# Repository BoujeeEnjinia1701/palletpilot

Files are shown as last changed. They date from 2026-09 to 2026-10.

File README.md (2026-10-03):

# PalletPilot

     

**Area:** Mobility and Logistics · **TRL:** 3 of 9 (proof of concept on paper) · **Value-engineering target:** $1,610 USD (estimated cost $5,065) · **Difficulty:** 4 of 5

Retrofit kit that turns a manual pallet jack into a powered, walk-behind unit with a UWB follow-me mode and layered stopping.

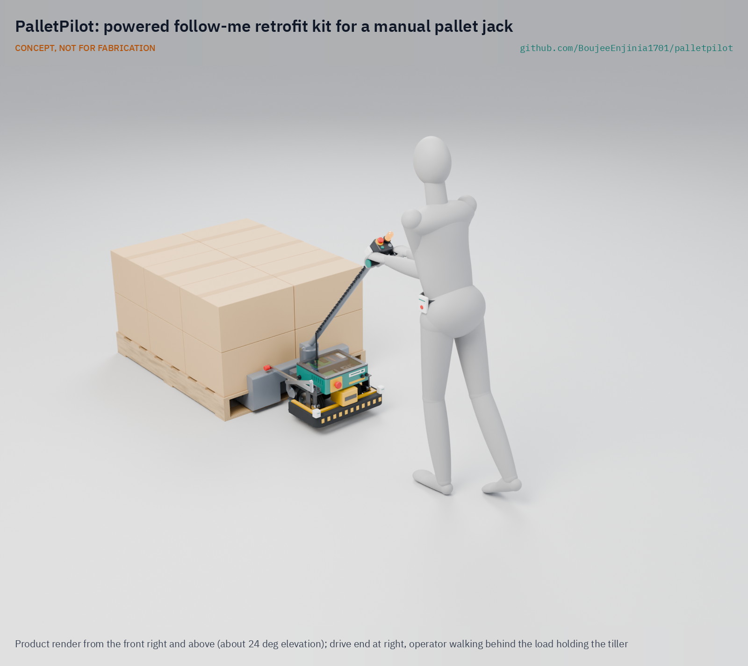
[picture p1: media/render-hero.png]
PalletPilot: powered follow-me retrofit kit for a manual pallet jack, product render


[Exploded render](media/render-exploded.png) · [Detail render](media/render-detail.png) · [Interactive 3D model](media/viewer.html) · [Concept blueprint (PDF)](media/concept-blueprint.pdf) · [General arrangement PLP-DWG-001 (PDF)](cad/drawings/PLP-DWG-001.pdf) · [Sizing calculations](docs/04-calcs/01-sizing.md) · [Prototype build plan](docs/05-build-plan.md) · [Design decisions](docs/06-design-decisions.md) · [Review note](docs/REVIEW.md)

## Concept rationale

Most small sites already own one or more manual pallet jacks, and the jack's forks, pump and load wheels already do the hard part: lifting and carrying the pallet. What the operator lacks is drive and, for picking, a way to stop walking back to the handle. A bolt-on drive module on the steering yoke adds both without touching the jack's load path, and it can be removed to restore the jack. The kit uses parts a small shop can buy or make: AGV hub motors, a 24 V LiFePO4 pack, folded sheet metal, a safety laser scanner and UWB modules.

Keeping the design open matters because the likely users have no dealer service contract. Published drawings, a priced bill of materials and the sizing script let a maintenance person repair it, adapt the clamp to another donor jack, and check the safety numbers for themselves. The kit is a research prototype, not a certified industrial truck.

## Burning platform

Moving loads by hand is one of the most common causes of work injury. In the United States, warehousing and storage recorded 4.8 injury and illness cases per 100 full-time workers in 2024 ([BLS, Warehousing and Storage](https://www.bls.gov/iag/tgs/iag493.htm)), about twice the private industry rate of 2.3 ([BLS, Employer-Reported Workplace Injuries and Illnesses](https://www.bls.gov/news.release/osh.nr0.htm)).

In the European Union, about three in five workers report musculoskeletal complaints, and 52 % of establishments name lifting or moving people or heavy loads as a risk factor ([EU-OSHA, Healthy Workplaces 2020 to 2022](https://healthy-workplaces.osha.europa.eu/en/previous-campaigns/musculoskeletal-disorders-2020-22/what-issue)). Powered trucks remove most of that effort, but small sites with a handful of staff are the ones least able to buy them.

## Where it could be used

### By industry

| Industry | Use |
| --- | --- |
| Small warehousing and third-party logistics | Staging, put-away and loading without a forklift or a second worker |
| Grocery and retail backrooms | Receiving early-morning deliveries and restocking aisles, often by one person |
| Beverage and food distribution | Short, repeated moves of heavy pallets from dock to cooler or truck |
| Light manufacturing and workshops | Moving raw stock and finished goods between machines |
| Maker spaces and training centers | Shared material handling and teaching of safe powered-truck practice |
| Agricultural packhouses | Moving filled crates and bins from packing lines to cold rooms |

### By country or region

| Country or region | Why it matters there |
| --- | --- |
| United States | Warehousing injury rate about twice the private industry average ([BLS](https://www.bls.gov/iag/tgs/iag493.htm)); [OSHA 1910.178](https://www.osha.gov/laws-regs/regulations/standardnumber/1910/1910.178) sets the training and modification-approval route |
| European Union | About three in five workers report musculoskeletal complaints ([EU-OSHA](https://healthy-workplaces.osha.europa.eu/en/previous-campaigns/musculoskeletal-disorders-2020-22/what-issue)); many small distributors and workshops share manual jacks |
| Japan | 29.3 % of the population was 65 or older on October 1, 2024 ([Statistics Bureau of Japan](https://www.stat.go.jp/english/data/jinsui/2024np/index.html)); cutting push force and walking helps older staff keep working |
| India | Scored 3.4 of 5 in the World Bank's 2023 Logistics Performance Index ([World Bank, Connecting to Compete 2023](https://documents1.worldbank.org/curated/en/099042123145531599/pdf/P17146804a6a570ac0a4f80895e320dda1e.pdf)); small distributors that still move pallets by hand could gain a low-cost, locally repairable retrofit instead of importing a complete powered truck |
| Brazil | Scored 3.2 of 5 in the 2023 Logistics Performance Index ([World Bank](https://documents1.worldbank.org/curated/en/099042123145531599/pdf/P17146804a6a570ac0a4f80895e320dda1e.pdf)); small wholesalers and supermarkets that move pallets by hand are the target users |
| South Africa | Scored 3.7 of 5 in the 2023 Logistics Performance Index ([World Bank](https://documents1.worldbank.org/curated/en/099042123145531599/pdf/P17146804a6a570ac0a4f80895e320dda1e.pdf)); distributors and packhouses could fit a kit built from commodity parts and maintain it locally |

## What sparked the idea

The starting point was Piaggio Fast Forward's gita, a personal cargo robot that went on sale on November 18, 2019 for $3,250. At the push of a button it pairs with its leader and uses visual sensors to follow them at up to about 2.7 m/s (6 mph), carrying up to about 18 kg (40 lb) ([Piaggio Fast Forward press release, October 15, 2019](https://www.globenewswire.com/news-release/2019/10/15/1929794/0/en/Piaggio-Fast-Forward-Introduces-the-All-New-gita-Robot.html)). At the other end of the scale, follow-me operation for pallets comes as an option on full order-picking trucks: Jungheinrich's easyPILOT Follow lets its low-level order pickers follow an operator who wears a control unit ([Jungheinrich](https://www.jungheinrich.com/en/press-events/press-releases/easypilot-follow-faster-order-picking-with-the-new-semi-automatic-control-unit-158956)). Nothing sat between them: a follow-me mode for a 1,000 kg pallet at a price a small site can pay. PalletPilot fills that gap by adding the follow-me mode, with layered stopping, to the manual jack the site already owns.

## Problem

Small warehouses move pallets by hand, and powered pallet trucks with follow-me modes cost more than they can justify. Starting a 1,000 kg pallet on a manual jack takes about 270 N (estimate, PLP-CAL-001), at or past common ergonomic push limits. Basic lithium walkies now cost about $1,640, but follow-me trucks are forklift-class products. Full problem statement: [docs/01-problem.md](docs/01-problem.md)

## Concept

Retrofit kit that turns a manual pallet jack into a powered, walk-behind unit with a UWB follow-me mode and layered stopping.

A sprung module with two 24 V hub motors clamps to the jack's steering yoke, with a 25.6 V 20 Ah LiFePO4 pack and the electronics in a low enclosure under the handle's sweep. In walk mode the operator steers with the handle and a walkie-style tiller head. With the kit fitted the handle turns about 40° each way, set by rubber stops (a bare jack turns about 90°), so the jack turns more widely than before: a turning radius of roughly 1.5 m about the load wheels, to be confirmed in the TRL 4 aisle test. In follow mode the operator wears a UWB tag and the motors steer by differential drive to hold a 1.5 m gap. Stopping is layered: a safety laser scanner watches a 0.80 m field ahead of the truck in follow mode, hardwired emergency stops act through a dual-channel safety relay and two contactors in series, and a contact bumper is the last layer.

The sizing note ([PLP-CAL-001](docs/04-calcs/01-sizing.md)) finds that the kit moves 1,000 kg, starts on a 2 % ramp, works a 60-move shift with 24 % of the pack left and stops from 0.6 m/s in 0.36 to 0.70 m. Two targets are missed on paper: follow bearing accuracy (about ±16° against ±10°) and the 40 kg kit mass goal (42.9 kg, inside the 45 kg prototype limit). Value-engineering target: USD 1,610. Estimated cost of the constructable design: USD 5,065 (USD 3,455 over the target), because personnel detection now uses a safety-rated laser scanner. With the kit fitted the jack steers about 40° each way, against about 90° bare. Requirement status is in [docs/03-requirements.md](docs/03-requirements.md); decisions are in [PLP-DDR-001](docs/decisions/0001-trl2-review-decisions.md) and [PLP-DDR-002](docs/decisions/0002-recommendations-accepted.md); the changes that made the design buildable are in [PLP-DDR-003](docs/decisions/0003-design-for-construction.md).

Full design precis: [docs/02-concept.md](docs/02-concept.md)

## Key components

- Drive module with two 24 V, 200 mm hub motors and spring-applied brakes
- Dual-channel motor driver
- 25.6 V 20 Ah LiFePO4 pack with BMS
- Tiller control head with throttle, belly-reverse paddle and mode key
- Two hardwired emergency stops, a safety relay and two main contactors
- Safety laser scanner (PL d class) for personnel detection in follow mode, to ISO 3691-4
- Contact bumper (safety edge) as the last layer
- Three UWB anchors and an operator tag
- ESP32-S3 class controller

The working bill of materials is in [bom/bom.csv](bom/bom.csv).

## Building the prototype

The [prototype build plan](docs/05-build-plan.md) (PLP-BLD-001) shows how to make each of the 17 components and fit them to a donor jack in 15 steps, with a making sketch for every made part, close-ups of the joints and a picture for every step. Eleven parts are cut, drilled, welded or folded in a small fabrication shop; the motors, battery, electronics, safety edge, safety scanner and tiller head are bought. The subframe grips the jack's yoke plate between a top plate and a bolted jaw, so nothing on the jack is drilled. It is a plan, not a record of a build: building and testing to it is TRL 4 work. Decisions still open are in the [design decisions register](docs/06-design-decisions.md).

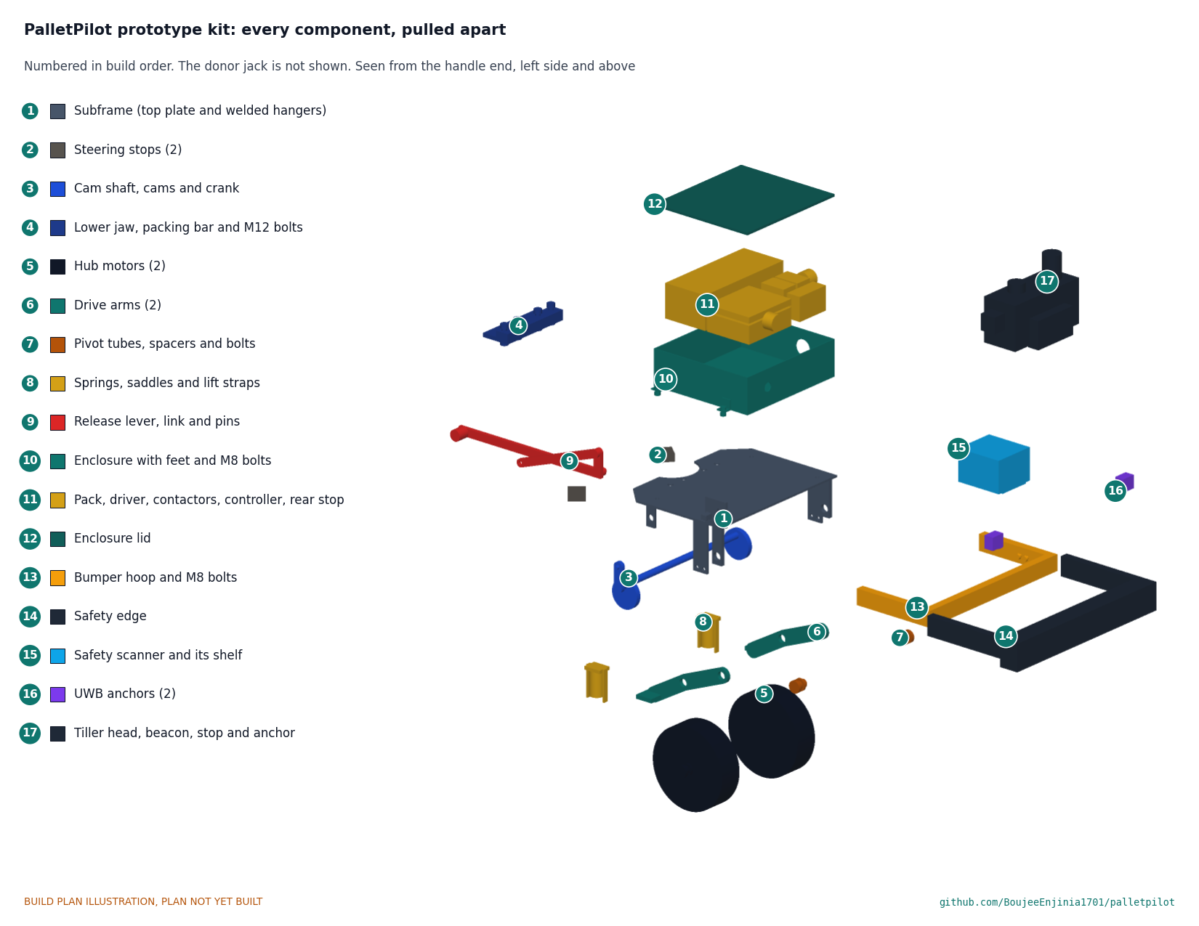
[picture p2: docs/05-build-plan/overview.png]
PalletPilot kit: every component pulled apart and numbered in build order


## Safety

> Moving machinery near people. The design uses hardwired emergency stops, walking-pace speed limits, a safety laser scanner stop layer in follow mode and a bumper that stops the unit on contact. The scanner layer is not yet built or tested, so follow mode stays at 0.15 m/s or less in a closed area until the layer is built and tested. Follow mode is treated as a driverless truck function under ISO 3691-4, so its personnel detection and stopping functions must meet that standard before any trial with people present. Contains a lithium battery pack. Use a BMS with cell-level protection, fuse the pack, and charge on a non-combustible surface. In the United States a powered pallet jack needs trained operators and the jack maker's written approval for modifications (29 CFR 1910.178). Builds are research prototypes, not certified industrial trucks. See [docs/02-concept.md](docs/02-concept.md#safety).

## Repository layout

| Folder | Contents |
| --- | --- |
| `docs/` | Problem, concept, requirements, calculations and design decisions |
| `cad/src/` | build123d Python source, the source of truth for all geometry |
| `cad/step/`, `cad/stl/` | Exported models for FreeCAD, other CAD tools and printing |
| `cad/drawings/` | General arrangement PLP-DWG-001 (generated by `cad/src/sheets.py`) |
| `bom/` | Bill of materials |
| `electronics/` | KiCad schematics and PCB layouts |
| `firmware/` | Microcontroller code |
| `media/` | Renders, perspectives and photos |
| `build-log/` | Dated prototyping notes |

## Documentation

Controlled documents follow the portfolio [documentation standard](.kit/STANDARDS.md). Each carries a document ID (PLP-PRC-001 for the precis), a version and a revision history. Branded PDFs are built with `python .kit/render.py` and attached to GitHub Releases when a document is tagged, for example `PLP-PRC-001/v1.0`.

## Credits

Designed by Amish Chadha. See [CONTRIBUTORS.md](CONTRIBUTORS.md) for roles. To cite this design, use [CITATION.cff](CITATION.cff) (GitHub shows it as "Cite this repository").

AI assistance (Claude) was used to accelerate concept renders, prototype documentation and first-pass sizing calculations. Design direction and all decisions are Amish Chadha's, recorded in this repository's decision records (`docs/decisions/`).

## Licenses

- **Hardware** (CAD, drawings, BOM, electronics): [CERN-OHL-S v2](LICENSE)
- **Software** (firmware, scripts, notebooks): [MIT](LICENSE-SOFTWARE)

A project of the [Design Molecule](https://designmolecule.com) lab.

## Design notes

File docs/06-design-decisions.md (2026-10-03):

---
doc_id: PLP-DEC-001
title: PalletPilot design decisions register
project: PalletPilot
doc_type: Design decisions register
version: "0.6"
status: Draft
date: '2026-10-03'
author: Amish Chadha
license: CERN-OHL-S-2.0
revisions:
  - version: "0.1"
    date: '2026-10-01'
    author: Amish Chadha
    change: Register opened with the build plan; open decisions from PLP-DDR-001 to 003 and the review note; budget treated as a value-engineering target
  - version: "0.2"
    date: '2026-10-01'
    author: Amish Chadha
    change: Amish accepted the recommendation of open item 1 (steering range, option a, with a TRL 4 aisle test as a go or no-go gate; PLP-DDR-003 A1); moved to decisions made; open items renumbered 1 to 5
  - version: "0.3"
    date: '2026-10-02'
    author: Amish Chadha
    change: "Amish approved the recommendations for all five open decisions; moved to decisions made; To confirm item 1 and the value engineering note updated"
  - version: "0.4"
    date: '2026-10-02'
    author: Amish Chadha
    change: "Design for construction (PLP-DDR-003, Table 1, P1 to P10) accepted by Amish on 2026-10-02; the 2026-09-30 row no longer says open for review"
  - version: "0.5"
    date: '2026-10-02'
    author: Amish Chadha
    change: "Approved follow-ups carried out: row added to decisions made; value engineering section restated (safety scanner, USD 5,065, 42.9 kg); To confirm items 4, 5 and 6 updated"
  - version: "0.6"
    date: '2026-10-03'
    author: Amish Chadha
    change: "Amish accepted the PL d safety scanner at USD 3,455 and the kit estimate of about USD 5,065 against the USD 1,610 target (2026-10-03); row added to decisions made; value engineering section updated"
---

# PalletPilot design decisions register

Every design decision still to be made, and every decision made, in one place. Each decision is argued in full in its decision record under `docs/decisions/`; this register is the index Amish works from. The build plan (`docs/05-build-plan.md`) describes the design as it stands and does not list open decisions.

## Open decisions

None. All open decisions were decided on 2026-10-02.

## To confirm when parts are bought

| # | What to confirm | Why it matters | Source |
| --- | --- | --- | --- |
| 1 | The donor jack's yoke plate thickness, rear edge position and width, the pump diameter, and the distance from the steering axis to the frame head, for each of the three jacks in the donor survey decided on 2026-10-02 (a Crown PTH 50 series class model, a distributor's standard model such as Uline's, the Harbor Freight Pittsburgh 5,500 lb jack) | They set the packing bar, the clamp holes, the notch and the steering stop angle | PLP-DDR-003; R1 |
| 2 | The hub motor's 24 V winding, peak torque (30 N·m or more), brake holding torque (20 N·m or more), mass and its shaft's diameter and flats | They set the drive arm's axle hole and the mass and stopping figures | PLP-DDR-002; PLP-CAL-001 |
| 3 | The preload spring: about 34 mm outside diameter, about 65 mm free length, about 100 N/mm | It sets the 750 N per wheel preload and the 10 mm wheel lift | PLP-DDR-003; PLP-CAL-001 [G4] |
| 4 | The safety edge profile's travel (40 mm or more at the front, now 68 mm high), its evaluation unit's category and response time | R8's 0.15 m/s limit rests on 40 mm of travel and a 100 ms chain | PLP-DDR-002; R8 |
| 5 | The tiller head fits the donor handle tube and carries the beacon, stop and anchor | The head clamps on the handle; the grip width is still open in the appearance model | REVIEW (2026-09-26) |
| 6 | The safety scanner's mounting holes, its scan plane height above its base (about 40 mm assumed), its response time (70 ms assumed) and the exact size of its body (about 107 x 80 x 118 mm assumed) | The bracket shelf is drilled to suit, they set the 173 mm scan plane and the 0.80 m protective field, and the body must clear the enclosure by 5 mm | PLP-DDR-003; ISO 3691-4 decision of 2026-10-02 |

## Value engineering

Value-engineering target: USD 1,610 (a hypothetical control target, not a limit). Estimated cost of the constructable design: USD 5,065 (USD 3,455 over the target). Main cost drivers and savings worth trying:

Amish accepted this overrun on 2026-10-03: the safety scanner line of USD 3,455 and the kit estimate of USD 5,065 against the USD 1,610 target (USD 3,455 over). Amish: "PalletPilot - i accept it". Amish: "Cost over target - i accept all the cost variations and overruns". It stays reported against the target as an accepted overrun, and the savings below remain worth trying.

- The safety laser scanner for personnel detection is USD 3,455 (USD 3,444.30 listed for a SICK nanoScan3 class unit, plus a shelf), 68 % of the kit. It replaced a USD 80 lidar line when Amish decided on 2026-10-02 that follow mode is treated under ISO 3691-4. The next largest lines are the two hub motors (USD 400), the battery (USD 180), the motor driver (USD 150), the drive module (USD 130) and the contact bumper (USD 110).
- Making the design constructable added USD 80: the drive module with its clamp, arms and pivot (USD 90 to USD 130), the release mechanism with its cams, link, springs and straps (USD 20 to USD 45), the enclosure feet (USD 5) and the steering stops (USD 10).
- The 5 mm top plate, tube lever and hollow pivots decided on 2026-10-02 are in the model and cut the kit mass by about 2.0 kg (kit now 42.9 kg); they change no price.
- Savings worth trying: a smaller or cheaper safety scanner that still meets PL d and fits in front of the enclosure (a refurbished Hokuyo UAM-05LP-T301 is listed at USD 1,347.53 but its 143 x 110 x 110 mm body does not fit as the kit is laid out), a motor sold with its driver as a pair (the class prices run from USD 165 to USD 249 per motor), and batching the laser-cut plate parts into one order.

## Decisions made

| Date | Decision | Decided by | Record |
| --- | --- | --- | --- |
| 2026-09-25 | TRL 2 review items D1 to D9: layered stopping with a low-cost lidar layer, budget, dual hub motors on a sprung yoke module, 24 V LiFePO4, everything on the yoke, speeds, kit rating, legal route, partner types | Amish: "proceed with all of your recommendations across all batches. Make sure we don't proceed to TRL 4 on any of them." | PLP-DDR-001 |
| 2026-09-25 | Bumper-only speed limited to 0.15 m/s (O4); mass and cost overruns accepted for now, R5 fixes evaluated at TRL 4 (O5); a second main contactor in series (O6) | Amish: "i accept all your recommendations, go with them across all repos." | PLP-DDR-002 |
| 2026-09-26 | Budget set to USD 1,610 to cover the priced BOM | Amish: "i approve all the budget items." | PLP-DDR-002 v0.2 |
| 2026-09-30 | Make the design physically buildable while drawing the build plan; outstanding decisions go in this register, not in the build plan | Amish: "If you are realising that the design cannot be built as per concept - fix the design assumptions to match and be physically feasible as you draw the illustrations." The changes themselves were accepted on 2026-10-02 (below) | PLP-DDR-003 |
| 2026-10-01 | The budget is a value-engineering target, reported as over or under, never as a limit | Amish: "the budgets are a hypothethical control target to ensure we are thinking along a value engineering lens." | This register; PLP-CAL-001 v0.4 |
| 2026-10-01 | Steering range (open item 1 in register v0.1): option (a). Accept about 40° each way with the kit fitted for the prototype (a bare jack turns about 90°), turning radius roughly 1.5 m about the load wheels; set the rubber stops from the donor survey; the precis, README and requirements no longer say the kit steers like the bare jack. **Go or no-go gate:** the TRL 4 aisle test must show the kit can make a right-angle turn into a standard pallet bay; if it cannot, the drive layout changes before TRL 5 (option c, for example one centre drive wheel under the yoke, which reopens D3) | Amish: "i accept your recommendations for PalletPilot" | PLP-DDR-003, A1 |
| 2026-10-02 | Kit mass of 44.4 kg accepted for the prototype (option a); R15's prototype limit restated as 45 kg, rechecked at the motor quote, and the 1.5 kg of savings of option (b) (5 mm top plate, tube lever, hollow pivot pin) carried into the TRL 4 drawings (open item 1) | Amish: "i approve your recommendations for all 555 open decisions." | PLP-DDR-003, A2 |
| 2026-10-02 | Drive wheel lift of 10 mm accepted for smooth indoor floors (option a); the build plan states that the release is for indoor floors only (open item 2) | Amish: "i approve your recommendations for all 555 open decisions." | PLP-DDR-003, A3 |
| 2026-10-02 | Follow mode is treated as a driverless truck function under ISO 3691-4, with personnel detection and stopping functions to that standard; it is reclassified as an operator-controlled assist mode only if a standards body or a notified body confirms that the walking follower counts as the operator (open item 3) | Amish: "i approve your recommendations for all 555 open decisions." | PLP-DDR-001, O2 |
| 2026-10-02 | Donor jacks to support first: a survey of three widely sold 27 x 48 in, 2,500 kg hand pallet jacks with published dimensioned drawings, a professional model such as the Crown PTH 50 series, a distributor's standard model such as Uline's, and the low-cost Harbor Freight Pittsburgh 5,500 lb jack (open item 4) | Amish: "i approve your recommendations for all 555 open decisions." | PLP-DDR-001, O3 |
| 2026-10-02 | Partners near Irving: Dallas Makerspace as the first candidate maker space, and a small food bank or charity warehouse in the Dallas and Fort Worth area as the first candidate warehouse, which trials only after the jack maker's written approval under D8 (open item 5) | Amish: "i approve your recommendations for all 555 open decisions." | PLP-DDR-001, O1 |
| 2026-10-02 | Design for construction accepted: the changes P1 to P10 in Table 1, as made | Amish: "APPROVED: Design-for-construction changes in 10 repos (CityTwin, CoolShade, PalletPilot, Heliolite, PotholeLog, EarthPress, ReadyKit, CellCheck, CargoMule and ThermaCart)" | [PLP-DDR-003](decisions/0003-design-for-construction.md), Table 1 |
| 2026-10-02 | Every follow-up action of the open-decision sign-off that needs CAD, drawing, picture, BOM or calculation work is carried out: the 5 mm top plate, tube lever and hollow pivots in the model; a safety laser scanner (SICK nanoScan3 class) in place of the lidar with the personnel stop to ISO 3691-4 stop category 1 and the R7 case rerun; R15a restated to 45 kg in the script. The donor survey dimensions (packing bar, clamp holes, notch, stop angle) wait for the surveyed jacks | Amish: "APPROVED CHANGES, COMPLETE THESE" | [REVIEW.md](REVIEW.md), session 2026-10-02 (approved follow-ups carried out) |
| 2026-10-03 | Safety laser scanner at PL d (SICK nanoScan3 class) at USD 3,455 accepted; the kit estimate of about USD 5,065 against the USD 1,610 value-engineering target (USD 3,455 over) accepted | Amish: "PalletPilot - i accept it"; and "Cost over target - i accept all the cost variations and overruns" | [REVIEW.md](REVIEW.md), session 2026-10-03; PLP-DEC-001, Value engineering |

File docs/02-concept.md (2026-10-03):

---
doc_id: PLP-PRC-001
title: PalletPilot design precis
project: PalletPilot
doc_type: Design precis
version: "0.9"
status: Draft
date: '2026-10-02'
author: Amish Chadha
license: CERN-OHL-S-2.0
revisions:
- version: "0.1"
  date: '2026-09-24'
  author: Amish Chadha
  change: Initial scaffold
- version: "0.2"
  date: '2026-09-25'
  author: Amish Chadha
  change: Populate to TRL 2 (architecture, first-order numbers, stopping analysis, safety, media)
- version: "0.3"
  date: '2026-09-25'
  author: Amish Chadha
  change: Record decisions PLP-DDR-001 (layered stopping with a lidar layer, budget, drive, power, mounting, speeds, rating, legal route); numbers replaced by PLP-CAL-001; layout revised for handle clearance and length
- version: "0.4"
  date: '2026-09-25'
  author: Amish Chadha
  change: Recommendations accepted by Amish (DDR-002)
- version: "0.5"
  date: '2026-09-26'
  author: Amish Chadha
  change: Budget approved by Amish ($1,610, PLP-DDR-002); cost status restated
- version: "0.6"
  date: '2026-10-01'
  author: Amish Chadha
  change: "Constructable design (PLP-DDR-003): drive module, release, mass, cost and steering range; budget as a value-engineering target"
- version: "0.7"
  date: '2026-10-01'
  author: Amish Chadha
  change: Steering range decided by Amish (PLP-DDR-003 A1, option a); range and turning radius stated in the summary and walk mode, with the TRL 4 aisle test as a go or no-go gate
- version: "0.8"
  date: '2026-10-02'
  author: Amish Chadha
  change: "Follow mode classification, donor survey, partners, R15 and wheel lift decided by Amish on 2026-10-02 (PLP-DEC-001)"
- version: "0.9"
  date: '2026-10-02'
  author: Amish Chadha
  change: "Approved follow-ups carried out: safety laser scanner replaces the lidar (ISO 3691-4), 5 mm top plate, tube lever and hollow pivots; mass, stopping and cost figures from PLP-CAL-001 v0.7"
---

# PalletPilot design precis

PalletPilot clamps a drive module with two 24 V hub motors to the steering yoke of an ordinary manual pallet jack, powers it from a 25.6 V LiFePO4 pack in a low enclosure on the same yoke, and adds a walkie-style tiller head, a UWB follow-me mode and layered stopping: hardwired emergency stops, a safety laser scanner stop layer in follow mode and a contact bumper as the last layer. The calculation note PLP-CAL-001 shows the kit can move a 1,000 kg pallet at walking pace for a full shift of 60 moves on one overnight charge, start on a 2 % ramp, and stop from follow-mode speed inside the scanner's field without reaching the operator it follows. Two targets are missed on paper: follow bearing accuracy (about ±16° against ±10°) and the 40 kg kit mass goal (42.9 kg, inside the 45 kg prototype limit). Value-engineering target: USD 1,610. Estimated cost of the constructable design: USD 5,065 (USD 3,455 over the target), because personnel detection now uses a safety-rated scanner. The design was made constructable on 2026-10-01 (PLP-DDR-003, Draft) and the prototype build plan is PLP-BLD-001; with the kit fitted the jack steers about 40° each way, set by rubber stops, against about 90° for a bare jack, so it turns more widely: a turning radius of roughly 1.5 m about the load wheels. Amish accepted this range for the prototype on 2026-10-01 (PLP-DEC-001); the TRL 4 aisle test confirms it and is a go or no-go gate for the drive layout. The scanner layer is not yet built or tested, so the kit is a research prototype for a closed area.

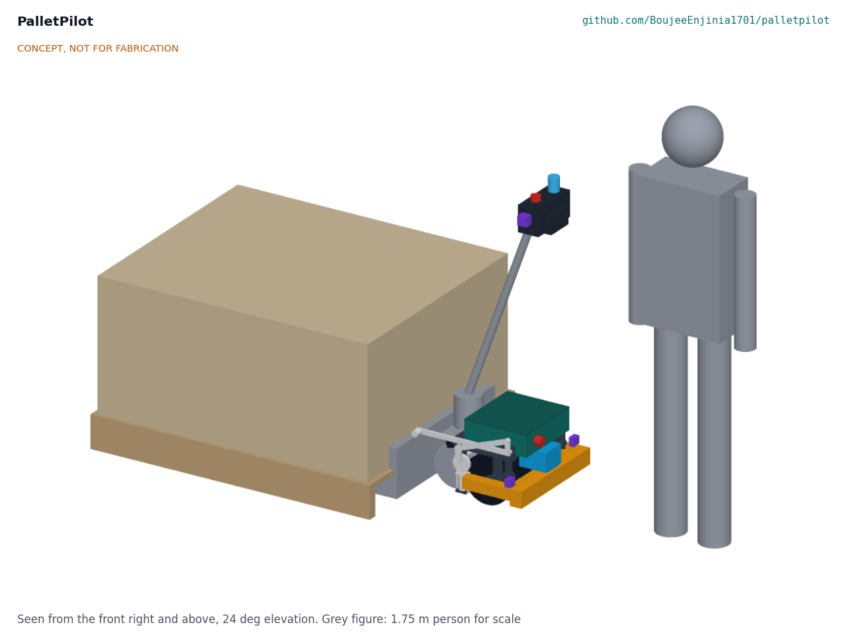
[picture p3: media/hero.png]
Hero render


*Figure 1. PalletPilot fitted to a 27 x 48 in manual jack under a 1,000 kg pallet, with a 1.75 m person for scale. Kit parts are colored; the donor jack is grey.*

## How it works

1. **Drive.** A steel subframe clamps to the jack's steering yoke: its top plate sits on the yoke plate with the pump in a notch, and a lower jaw bolted to it grips the yoke plate from below, so nothing is drilled in the jack. Two 200 mm hub motors sit on drive arms that each pivot on a hollow tube behind the wheel, 180 mm from the steering axis toward the handle end, on a 260 mm track that passes beside the steer wheels. Springs at the arms' front ends press them onto the floor with 1.5 kN of preload. They turn with the yoke, so the kit steers with the handle; rubber stops limit the turn to about 40° each way, where the bare jack turns about 90° (PLP-DDR-003).
2. **Walk mode.** The operator holds the tiller as usual and sets speed with a thumbwheel. As on a factory walkie, drive is enabled only with the handle between about 20° and 70° from vertical, a belly-reverse paddle pushes the truck away if it pins the operator, and releasing the handle to upright brakes the truck. The two motors run at equal torque so the handle steers freely, but not as far as on a bare jack: two rubber stops limit the turn to about 40° each way, for a turning radius of roughly 1.5 m about the load wheels (to be confirmed in the TRL 4 aisle test).
3. **Follow mode.** With the key switch set to follow and the handle latched upright by a gas spring, the operator walks ahead of the drive end wearing a UWB tag. Two anchors on the bumper corners and one on the tiller head measure range to the tag. The controller turns the two motors at different speeds while the truck rolls, and this steers the yoke toward the tag. It holds a 1.5 m gap, stops when the operator stops, and stops if the tag is lost, the tag's stop button is pressed or the gap exceeds 3 m.
4. **Layered stopping.** In follow mode a safety laser scanner just inside the bumper face watches a 0.80 m protective field ahead of the truck, 885 mm wide; when anything enters it, the scanner signals the safety relay, which commands a controlled stop (stop category 1, ISO 3691-4) and then lets the brakes close; a longer warning field slows the truck first. The contact bumper, the two emergency stops and the tag stop open a dual-channel safety relay that drops two main contactors in series, and the spring-applied hub motor brakes close when power is removed.
5. **Charge.** A certified 29.2 V, 5 A charger fills the pack from a wall outlet in about 4.5 h overnight.
6. **Push by hand.** Raising a release lever turns a cam shaft that lifts the spring saddles; slotted straps then lift the drive arms, so the drive wheels clear the floor by about 10 mm (enough for smooth indoor floors only, decided 2026-10-02) and the jack can be pushed as a manual jack if the pack is flat or the kit fails.

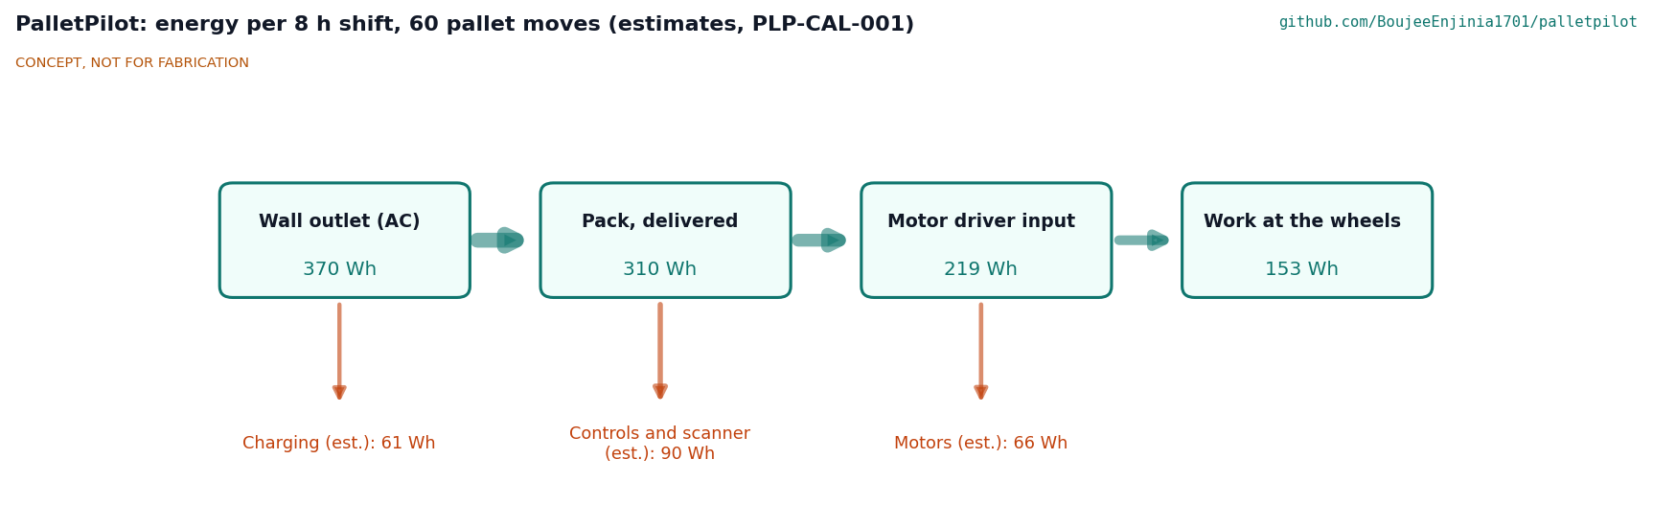
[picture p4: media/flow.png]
Energy flow


*Figure 2. Energy per 8 h shift of 60 pallet moves, in Wh, from PLP-CAL-001. All values are estimates.*

## Main components

Numbers match the exploded view (Figure 3), `bom/bom.csv` and drawing PLP-DWG-001.

Table 1. Main components.

| # | Component | Choice | Notes |
| --- | --- | --- | --- |
| 1 | Drive module | 5 mm steel top plate on the yoke plate with a notch round the pump, a lower jaw and four M12 bolts gripping the yoke; two drive arms, each on a hollow tube pivot behind its wheel; two springs at the arm fronts giving 1.5 kN preload | Clamp fit per donor model; about 8.9 kg (PLP-DDR-003) |
| 2 | Hub motors | Two 24 V brushless hub servo motors, 200 mm, 12 N·m continuous and 30 N·m peak or more, spring-applied brakes of 20 N·m or more | About 7 kg each; brake data to confirm |
| 3 | Enclosure | 2 mm aluminium box 270 x 300 x 96 mm, IP54, top at 320 mm, below the 350 mm handle pivot | Turns with the yoke; never on the forks |
| 4 | Battery | 8S6P LiFePO4, 25.6 V, 20 Ah (512 Wh), BMS with charge temperature cut-off | About 4.9 kg |
| 5 | Motor driver | Dual-channel 24 V servo driver, 2 x 15 A continuous, 30 A peak, CAN | Differential control for follow mode |
| 6 | Contactors, fuse and disconnect | 80 A fuse, two main contactors in series with pre-charge, lockable disconnect | One contactor per safety relay channel (PLP-DDR-002) |
| 7 | Controller and safety relay | ESP32-S3 class controller; dual-channel safety relay | Software never closes the stop chain alone |
| 8 | Tiller control head | Thumbwheel throttle, belly-reverse paddle, mode key, horn, beacon mount | Replaces the jack's grip |
| 9 | Emergency stops | Two red mushroom buttons, tiller head and enclosure rear face | Hardwired |
| 10 | Contact bumper | Pressure-sensitive safety edge, 40 mm travel, on a U hoop around the drive end | Last stopping layer |
| 11 | UWB anchors | Three DWM3000 class modules: two on the bumper corners (450 mm baseline), one on the tiller head | Range about 10 cm precision ([Qorvo](https://www.qorvo.com/products/p/DWM3000)) |
| 12 | Status beacon and buzzer | On the tiller head; amber in walk mode, blue in follow mode | Moved off the lid for handle clearance |
| 13 | Manual release | 400 mm over-center steel tube lever turns a cam shaft through a link; the cams raise the spring saddles and straps lift the drive wheels about 10 mm | About 58 N peak effort |
| 18 | Safety laser scanner | Safety laser scanner for personnel detection (SICK nanoScan3 class: Type 3, PL d, SIL 2, 3 m protective field, 70 ms response), on a shelf above the bumper hoop, scan plane about 173 mm above the floor | Replaces the lidar after the ISO 3691-4 decision of 2026-10-02; USD 3,444.30 listed ([Lesman](https://www.lesman.com/nans3-aaaz30an1)); not yet built or tested |
| 14 to 17 | Charger, operator tag, handle sensor and gas spring, wiring | See `bom/bom.csv` | Not modelled |

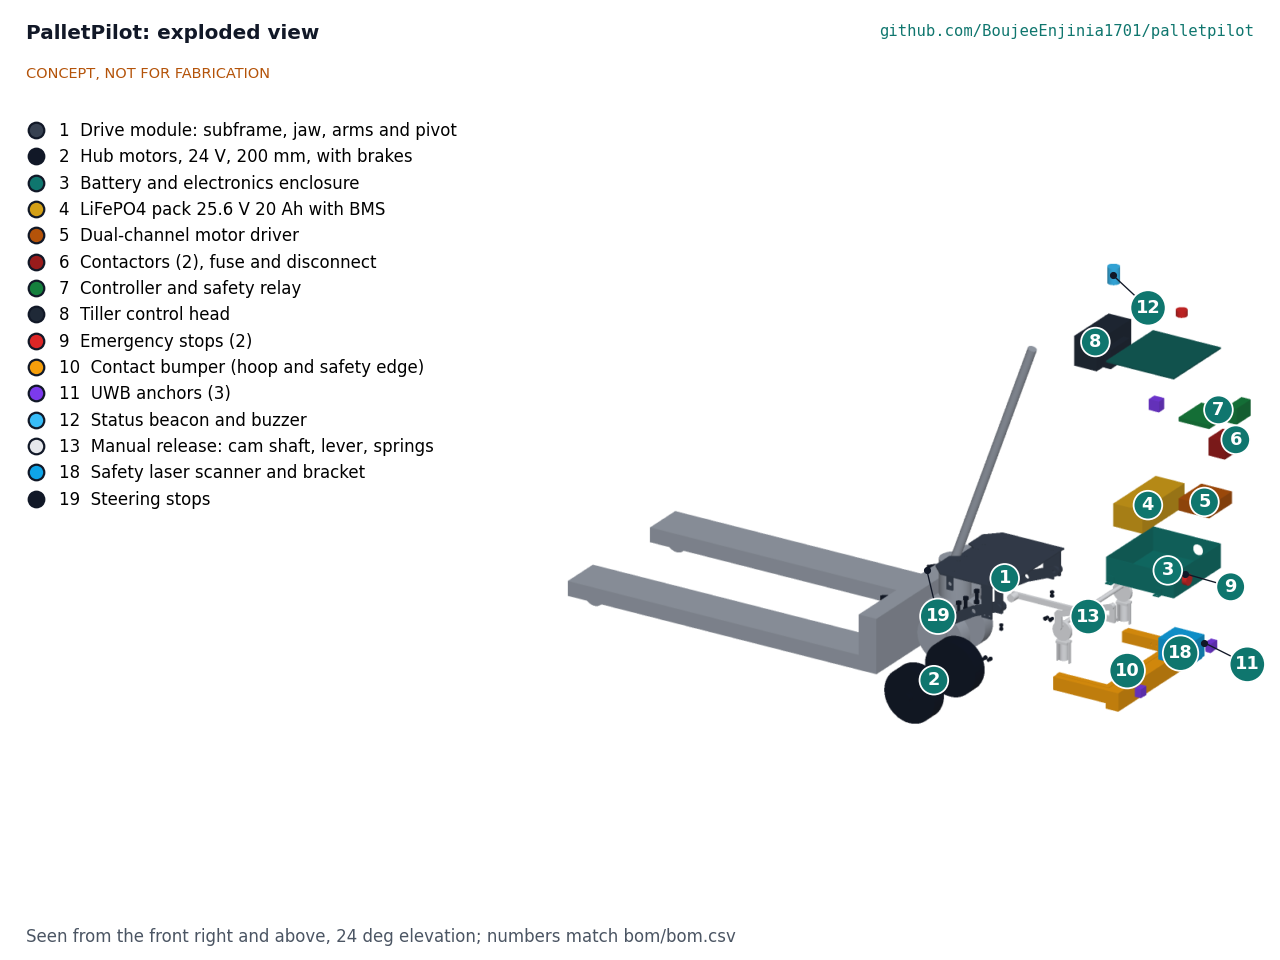
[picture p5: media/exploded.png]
Exploded view


*Figure 3. Exploded view with numbered callouts matching the BOM. The donor jack is grey and stays in place.*

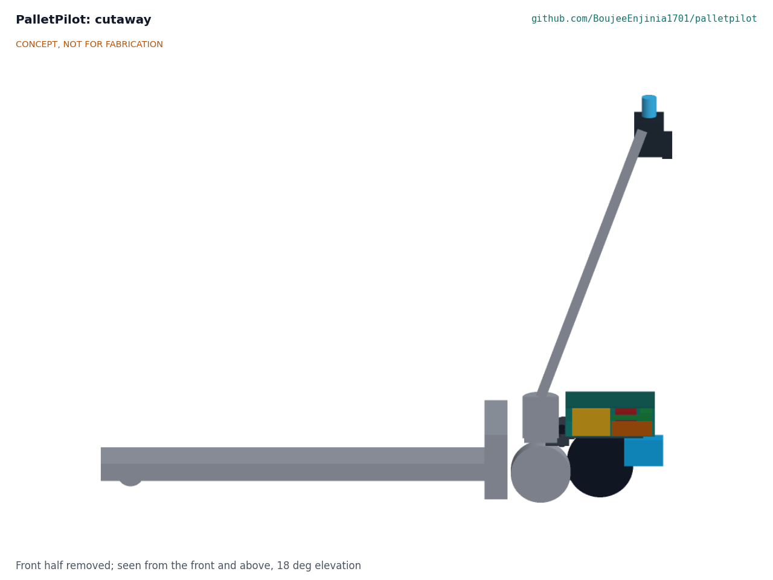
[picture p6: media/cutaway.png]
Cutaway


*Figure 4. Section through the center of the kit, showing the pack (yellow), motor driver (orange), contactors (red) and controller (green) in the low enclosure, and the safety scanner (blue) under its rear edge.*

## Key numbers

All values come from PLP-CAL-001, which lists its assumptions and the full requirement table. The design load case is 1,107 kg in total (1,000 kg pallet, 64 kg jack, 42.9 kg kit) on level, dry, sealed concrete.

Table 2. Drive, stopping, tracking, energy, mass and cost.

| Quantity | Value | Requirement |
| --- | --- | --- |
| Rolling and breakaway force, level | 130 N and 271 N | |
| Available traction (1.5 kN preload, friction 0.5) | 750 N (600 N at friction 0.4) | |
| 2 % ramp start | 489 N needed, margin 1.54 | R3 met |
| Torque per motor, worst case in R2 and R3 | 25.5 N·m of 30 N·m specified | R2 met; 1,500 kg on level floors only |
| Peak wheel power and pack current | 555 W; 31 A | Driver and BMS adequate |
| Scanner stop from 0.6 m/s | 0.36 m level; 0.70 m at 1,500 kg on a 2 % downgrade (1.15 m on brakes alone) | R7 at risk (0.80 m field) |
| Emergency stop from 1.2 m/s | 1.62 m level; 2.67 m on a 2 % downgrade | |
| Bumper-only speed limit | 0.15 m/s; stops in 38 mm of 40 mm travel | R8 met |
| Parking brake on 2 % | 40 N·m available, 21.7 N·m needed | R10 met |
| UWB bearing error | ±16° (2σ) after filtering | R5 not met |
| Energy from the pack per shift | 310 Wh of 410 Wh usable (24 % left) | R12 met |
| Charge time at 5 A | 4.5 h | R13 met |
| Handle clearance over the enclosure | 40 mm at 70°, 14 mm lowered flat | R11 met |
| Added length at floor level | 290 mm | R15 length met |
| Kit mass | 42.9 kg | R15 met for the prototype (45 kg limit, decided 2026-10-02); 2.9 kg over the 40 kg goal |
| Kit parts cost | $5,065 | USD 3,455 over the USD 1,610 value-engineering target |
| Donor jack (not in kit) | about $396 new | |

Three findings shaped the TRL 3 layout. First, the TRL 2 enclosure sat above the handle pivot, so the handle would have struck it at about 51°, inside the walk band; the enclosure is now lower and the beacon and second emergency stop have moved. Second, 1.1 kN of preload left the 2 % ramp at risk, so it is now 1.5 kN; with the jack empty the steer wheels then lift slightly and the drive wheels carry the yoke, which is acceptable. Third, because the drive axle is offset from the steering axis, the motors cannot swing the yoke at standstill (98 N·m available against 135 N·m of scrub), so follow mode steers only while rolling, and hand steering at standstill is about 112 N heavier at the grip.

For comparison, a complete 1,500 kg lithium walkie costs about $1,640 ([Home Depot](https://www.homedepot.com/p/3300-lbs-24V-20AH-Lithium-Battery-Electric-Pallet-Jack-Walkie-Truck-w-48-in-x-27-in-Fork-Size-3-1-in-Fork-Lowered-A-1034/326396102)) and the PowerPallet 2000 retrofit about $2,084 ([HoF Equipment](https://hofequipment.com/PowerHandling-Power-Pallet-2000-p1957.html)). The kit's case rests on follow mode and on reusing jacks a site already owns.

## Key design choices

Amish decided the TRL 2 review items on 2026-09-25 (PLP-DDR-001), going with each recommendation.

- **Layered stopping (D1).** A 2D lidar was chosen as the main stopping layer in follow mode, the bumper is the last layer, follow mode runs at 0.6 m/s or less, and trials are for research in a closed area. On 2026-10-02 the lidar was replaced by a safety-rated laser scanner, the named route to workplace use, when follow mode was classed as a driverless truck function under ISO 3691-4. The pitch now reads "layered stopping".
- **Budget (D2).** $1,550 for the kit, donor jack excluded; raised to $1,610 by Amish on 2026-09-26 to cover the priced BOM (PLP-DDR-002).
- **Drive layout (D3).** Two hub motors on a sprung module on the yoke, differential drive in follow mode.
- **Power (D4).** 24 V LiFePO4, 20 Ah, not a SwapCell pack; the SwapCell interface changes approved for the portfolio do not apply.
- **Mounting (D5).** Everything on the yoke, now checked for handle clearance (R11 met) and steering bearing load (no added vertical load; up to 750 N horizontal).
- **Speeds (D6).** Walk 1.2 m/s handle-end first, 0.8 m/s forks first, creep 0.3 m/s, follow 0.6 m/s. Until the scanner layer is built and tested, follow mode runs at 0.15 m/s or less, the bumper-only limit below.
- **Kit rating (D7).** 1,000 kg design load; 1,500 kg at 0.8 m/s or less. PLP-CAL-001 limits the 1,500 kg rating to level floors.
- **Legal route (D8).** Research use now; a jack maker's written approval before any workplace trial.
- **TRL 3 sizing choices** made in v0.3, within the decided configuration: preload 1.5 kN, motor torque and brake minimums, enclosure height, drive axle position and track, and the scanner's position.

Amish decided the items raised at TRL 3 on 2026-09-25 (PLP-DDR-002), again going with each recommendation.

- **Bumper-only speed (O4).** Any operation that relies on the bumper alone is limited to 0.15 m/s; the 40 mm edge is kept rather than a 65 mm edge that would push the added length past 300 mm.
- **Overruns (O5).** The 2.0 kg mass and $60 cost overruns are accepted for now and rechecked when a motor is quoted. The cost overrun is closed by the $1,610 budget Amish approved on 2026-09-26. Closing the R5 bearing gap (angle-of-arrival UWB or lidar leg tracking) is to be evaluated at TRL 4, which is on hold.
- **Stop chain (O6).** A second main contactor in series, one per safety relay channel, for about $30.

Decided on 2026-10-02 (PLP-DEC-001): follow mode is treated as a driverless truck function under ISO 3691-4; the donor survey covers a Crown PTH 50 series class jack, a distributor's standard model such as Uline's and the Harbor Freight Pittsburgh 5,500 lb jack; the first candidate partners to approach are Dallas Makerspace and a small food bank or charity warehouse in the Dallas and Fort Worth area.

## Safety

> **Safety:** PalletPilot is moving machinery that carries up to 1.5 t close to people's feet and legs, and it contains a lithium battery. Every build is a research prototype for a closed test area, not a certified industrial truck. Do not use it in a workplace until the questions below are answered.

- **Crushing and collision.** A loaded jack at 1.2 m/s carries about 796 J and needs 1.2 to 1.6 m to stop on the level, and 2.7 m on a 2 % downgrade. Foot injuries under the drive end and pinning against racking or walls are the classic walkie hazards. Use the belly-reverse paddle, handle-angle braking, walking-pace speed limits, safety footwear and a bumper hoop that shields the wheels. Never ride on the jack.
- **Follow mode.** The truck moves with no hand on the tiller. The scanner layer is a safety-rated class part, but its detection of dark or shiny clothing at shin height is unproven until it is built and tested. Until it is built and tested, follow mode runs only at 0.15 m/s or less, the bumper-only limit, in a cordoned area with no other people present. Loss of the tag, a tag stop press, a gap over 3 m, a scanner fault or any other fault must stop the truck with brakes applied. Follow mode is treated as a driverless truck function under ISO 3691-4 (decided 2026-10-02), so its personnel detection and stopping functions must meet that standard before any trial with people present.
- **Emergency stop.** The emergency stops and bumper act through a hardwired dual-channel safety relay and two main contactors in series, never only through software. The spring-applied brakes close on loss of power. The performance level (target PL d) is still to be calculated.
- **Runaway on slopes.** Emergency braking falls by about 40 % on a 2 % downgrade. Do not use on ramps steeper than 2 %, and do not move 1,500 kg loads on any ramp.
- **Lithium pack.** LiFePO4 is more stable than other lithium-ion chemistries but still stores 512 Wh and can deliver very high currents. Use a BMS with cell-level protection and a charge temperature cut-off, fuse the pack at the terminal, provide a lockable disconnect, charge on a non-combustible surface away from stored goods, and do not charge below 0 °C or a pack that is damaged or swollen.
- **Legal and training.** In the United States a motorized pallet jack is a powered industrial truck, so operators need formal training and evaluation under 29 CFR 1910.178(l), and modifications affecting capacity or safe operation need the jack maker's prior written approval under 1910.178(a)(4) ([OSHA 1910.178](https://www.osha.gov/laws-regs/regulations/standardnumber/1910/1910.178)). Other countries have similar rules. The kit must not be fitted to a jack used at work without that approval.
- **Donor jack condition.** Do not convert a jack with a cracked frame, a leaking pump or a worn steering bearing. The drive adds up to 750 N of horizontal force at the yoke.

## Open questions

- Personnel detection and stopping functions to ISO 3691-4 for follow mode (classified as a driverless truck function on 2026-10-02): which safety-rated sensor and what performance level.
- Donor survey of three jacks (decided 2026-10-02: a Crown PTH 50 series class model, a distributor's standard model such as Uline's and the Harbor Freight Pittsburgh 5,500 lb jack): yoke geometry, handle pivot height (the enclosure clears a 350 mm pivot by 14 mm), steering bearing condition.
- Floor friction and rolling resistance on real floors, which set the traction margins.
- Hub motor with a published 24 V winding, peak torque and brake torque at about 7 kg or less.
- Closing the R5 bearing gap: angle-of-arrival UWB or scanner leg tracking.
- PL calculation of the two-contactor stop chain (R9).
- Rechecking the $60 cost and 2.0 kg mass overruns at a motor quote.

Concept media: [blueprint sheet](../media/concept-blueprint.pdf), [interactive 3D model](../media/viewer.html). General arrangement: [PLP-DWG-001](../cad/drawings/PLP-DWG-001.pdf).

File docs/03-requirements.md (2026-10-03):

---
doc_id: PLP-REQ-001
title: PalletPilot requirements
project: PalletPilot
doc_type: Requirements
version: "0.9"
status: Draft
date: '2026-10-02'
author: Amish Chadha
license: CERN-OHL-S-2.0
revisions:
- version: "0.1"
  date: '2026-09-24'
  author: Amish Chadha
  change: Initial scaffold
- version: "0.2"
  date: '2026-09-25'
  author: Amish Chadha
  change: First measurable requirements for TRL 2, with status against the concept estimates
- version: "0.3"
  date: '2026-09-25'
  author: Amish Chadha
  change: Record decisions PLP-DDR-001 (R7 redefined for the lidar layer, R17 to $1,550, 1,500 kg on level floors); status from PLP-CAL-001
- version: "0.4"
  date: '2026-09-25'
  author: Amish Chadha
  change: Recommendations accepted by Amish (DDR-002)
- version: "0.5"
  date: '2026-09-26'
  author: Amish Chadha
  change: Budget approved by Amish
- version: "0.6"
  date: '2026-10-01'
  author: Amish Chadha
  change: "Constructable design (PLP-DDR-003): mass, release and cost figures; R17 reported against the value-engineering target"
- version: "0.7"
  date: '2026-10-01'
  author: Amish Chadha
  change: TRL 4 verification note for the steering range decided by Amish (PLP-DDR-003 A1); no requirement changed
- version: "0.8"
  date: '2026-10-02'
  author: Amish Chadha
  change: "R15 prototype mass limit restated as 45 kg and R7 tied to ISO 3691-4, decided by Amish on 2026-10-02 (PLP-DEC-001)"
- version: "0.9"
  date: '2026-10-02'
  author: Amish Chadha
  change: "Approved follow-ups carried out: R7 now names a safety laser scanner and the ISO 3691-4 stop; kit mass 42.9 kg after the 5 mm top plate, tube lever and hollow pivots; cost USD 5,065 with the scanner; figures from PLP-CAL-001 v0.7"
---

# PalletPilot requirements

These requirements are checked by calculation in PLP-CAL-001. Eleven of eighteen requirement lines are met on paper, one is not met (R5 bearing accuracy), two are at risk (R7, R9), three cannot be verified at TRL 3 (R1, R6, R16), and R17 is reported against its value-engineering target. Targets are still to be validated with users after site visits (see PLP-PRB-001). Decisions recorded in PLP-DDR-001 on 2026-09-25 changed R2, R4, R7 and R17; decisions in PLP-DDR-002 on the same date restated R4 and R8 (bumper-only and untested follow mode at 0.15 m/s) and R9 (two contactors in series). On 2026-09-26 Amish approved the budget of $1,610 (PLP-DDR-002); on 2026-10-01 he set budgets as value-engineering targets, not limits, so R17 is reported as over or under the target. On 2026-10-01 the design was made constructable (PLP-DDR-003, Draft): the kit mass and cost rose and the release lever was resized; no requirement changed status. On 2026-10-02 Amish restated R15's prototype mass limit as 45 kg, which the kit meets, and decided that follow mode is a driverless truck function under ISO 3691-4 (R7) (PLP-DEC-001). The same day the approved follow-ups were carried into the design: a safety laser scanner for personnel detection in place of the lidar (R7, R9, cost), and the 5 mm top plate, tube lever and hollow pivots (R15 mass); no requirement changed status.

The **design load case** is a 1,000 kg pallet on a 64 kg donor jack with a kit of about 42.9 kg, about 1,107 kg in total, on a level, dry, sealed concrete floor.

The **design duty** is one 8 h shift of 60 pallet moves, each 40 m loaded and 40 m empty, with four starts in each direction.

Table 1. Requirements.

| ID | Requirement | Target | Verification | Status (PLP-CAL-001) |
| --- | --- | --- | --- | --- |
| R1 | Fit a common manual jack | Bolts to 27 x 48 in (685 x 1220 mm), 2,500 kg manual jacks with a common steering yoke; no welding, cutting or drilling of load-bearing parts; fitted in 2 h or less and removed in 1 h or less with hand tools | Survey of three donor models; fitting sequence review | Not verifiable at TRL 3; the model assumes one donor geometry |
| R2 | Move the design load | Start and move 1,000 kg on a level floor; kit rating 1,500 kg at 0.8 m/s or less on level floors, below the donor rating (decided, PLP-DDR-001 D7) | Traction and torque calculation | Met: 25.5 N·m per motor needed of 30 N·m specified; 750 N traction. A 1,500 kg ramp start is outside the rating |
| R3 | Handle short ramps | Start, climb and hold the design load on a 2 % grade | Traction, torque and brake calculation | Met: start needs 488 N of 750 N (margin 1.54, 1.23 at friction 0.4) |
| R4 | Walking-pace speeds | Walk mode 1.2 m/s (4.3 km/h) or less handle-end first and 0.8 m/s or less forks first; creep 0.3 m/s or less with the handle near upright; follow mode 0.6 m/s or less, and 0.15 m/s or less until the scanner layer is built and tested (decided, PLP-DDR-001 D6; interim limit lowered from 0.2 m/s to the bumper-only limit by PLP-DDR-002) | Controller limits; later timed runs | Met by design (software limits) |
| R5 | Follow the operator | In follow mode, hold a 1.5 m gap within ±0.3 m and a bearing within ±10° (2σ) of the tag at walking pace | UWB error budget; later tracking trials | **Not met**: gap ±0.06 m, but bearing about ±16° with a 450 mm anchor baseline and filtering |
| R6 | Stop if the operator is lost | Stop command within 0.3 s of losing the tag link, a gap over 3 m, a tag stop press or the tag leaving a ±45° cone | Firmware design review; later bench test | Not verifiable at TRL 3; timing budget 0.20 s |
| R7 | Stop before hitting a person in follow mode | The safety scanner layer detects a person in the travel path and the truck stops without contact from 0.6 m/s with the design load, with the bumper as the last layer (layer redefined for option 1A, D1; the lidar was replaced by a safety-rated scanner after the ISO 3691-4 decision of 2026-10-02) | Stopping calculation; later test with an ISO 3691-4 test piece; follow mode is treated as a driverless truck function under ISO 3691-4 (decided 2026-10-02), so personnel detection and stopping must meet that standard | **At risk**: controlled stop 0.36 m level and 0.70 m worst case, inside a 0.80 m protective field, with a PL d class scanner chosen (SICK nanoScan3 class); if the drive's controlled stop failed and only the brakes acted, the worst case needs 1.15 m, beyond the field; the performance level of the whole stopping function is not calculated |
| R8 | Stop on bumper contact | Bumper contact removes drive power and applies the brakes within 100 ms; any operation that relies on the bumper alone limited to 0.15 m/s or less (decided, PLP-DDR-002; was 0.2 m/s) | Stop chain design review | Met on paper: 0.10 s chain; 0.15 m/s stops in 38 mm of the 40 mm edge travel |
| R9 | Emergency stop | Two hardwired emergency stops (tiller head and enclosure) plus the tag stop; the hardwired stops cut drive power through a dual-channel safety relay and two main contactors in series (decided, PLP-DDR-002), independent of software; target performance level PL d under ISO 13849-1 | Stop chain review; PL calculation | **At risk**: dual-channel relay and two contactors in series; PL not yet calculated |
| R10 | Park safely | Brakes apply with power off and hold the design load on a 2 % grade | Brake torque check against datasheet | Met on paper: 40 N·m specified against 21.7 N·m needed; datasheet to confirm |
| R11 | Keep the operator in control | Walk mode drives only with the handle between about 20° and 70° from vertical; belly-reverse paddle on the tiller head reverses the truck when pressed | Design review; model check | Met: the handle clears the enclosure by 40 mm at 70° and 14 mm when lowered flat |
| R12 | Work a full shift | Complete the design duty on one charge with 20 % or more of usable energy left | Energy calculation | Met: 293 Wh used of 410 Wh usable (28 % left) |
| R13 | Charge overnight | Full charge in 5 h or less from a 120 V or 230 V outlet through a certified charger | Charger datasheet | Met: 4.5 h at 5 A |
| R14 | Push by hand when unpowered | One lever lifts the drive wheels clear in 10 s or less (brakes need no release once the wheels are clear); unpowered push force no more than 10 % above the bare jack | Design review; later push-force test | Met on paper: +4.0 % push force; peak lever effort about 58 N; drive wheels lift about 10 mm (PLP-DDR-003) |
| R15 | Keep the jack usable | Kit mass 40 kg or less as the goal, 45 kg or less for the prototype (decided 2026-10-02, PLP-DEC-001); overall length increase 300 mm or less at floor level; lowered fork height and pallet entry unchanged | Mass estimate; model check | Met for the prototype: 290 mm added length (met); 42.9 kg, 2.1 kg under the 45 kg prototype limit and 2.9 kg over the 40 kg goal; rechecked at the motor quote |
| R16 | Indoor environment | Operate at 0 to 40 °C; electronics and connectors IP54; no charging below 0 °C | Datasheets and design review | Not verifiable at TRL 3; set by the specification of bought parts |
| R17 | Affordable | Kit parts cost against the value-engineering target of $1,610, donor jack excluded (budget decided, D2; $1,610 approved by Amish, 2026-09-26, PLP-DDR-002; a target, not a limit, 2026-10-01) | Priced BOM (`bom/bom.csv`) | Value-engineering target: USD 1,610. Estimated cost of the constructable design: USD 5,065 (USD 3,455 over the target) |

## Requirements not met or at risk

- **R5, follow bearing accuracy, is not met.** Filtering brings the error to about ±16°; ±10° would need a 706 mm anchor baseline, wider than the jack. Amish decided to evaluate angle-of-arrival modules and scanner leg tracking at TRL 4, which is on hold (PLP-DDR-002).
- **R15 mass is met for the prototype** (45 kg limit) and misses the 40 kg goal by 2.9 kg. The 30 N·m class hub motors weigh about 7 kg each; the second contactor adds 0.3 kg; the parts added to make the design constructable (clamp jaw, drive arms, pivots, cam shaft and lever) add 2.4 kg (PLP-DDR-003). Amish accepted 2.0 kg over for now, to be rechecked at the motor quote (PLP-DDR-002); on 2026-10-02 he accepted 44.4 kg for the prototype and set R15's prototype limit at 45 kg, with the savings (5 mm top plate, tube lever, hollow pivots) carried into the model on the same day: they take out about 2.0 kg, the safety scanner adds 0.4 kg, and the kit is now 42.9 kg (PLP-DEC-001; PLP-CAL-001 v0.7). The 40 kg goal is still not met.
- **R17, cost, is USD 3,455 over its value-engineering target**: USD 5,065 against USD 1,610. USD 3,375 of it is the safety laser scanner that replaced the USD 80 lidar line (listed price of a SICK nanoScan3 class unit, USD 3,444.30). Savings worth trying are listed in PLP-DEC-001.
- **Steering range (no requirement covers it; verified at TRL 4).** With the kit fitted the jack steers about 40° each way, set by rubber stops, against about 90° for a bare jack, for a turning radius of roughly 1.5 m about the load wheels (PLP-DDR-003, P9). Amish accepted this range for the prototype on 2026-10-01 (PLP-DDR-003, A1). Verification: the TRL 4 aisle test, a go or no-go gate. Pass when the loaded kit makes a right-angle turn from an aisle into a standard pallet bay; if it cannot, the drive layout changes before TRL 5 (PLP-DEC-001).
- **R7 is at risk.** The controlled-stop distances fit the scanner's protective field on paper and the scanner is a PL d, Type 3 class part, but the performance level of the whole stopping function is not calculated, and the brakes-only worst case (1.15 m) exceeds the 0.80 m field, so this cannot yet support an ISO 3691-4 claim. On 2026-10-02 Amish decided that follow mode is treated as a driverless truck function under ISO 3691-4, so personnel detection and stopping functions must meet that standard; it is reclassified as an operator-controlled assist mode only if a standards body or a notified body confirms that the walking follower counts as the operator (PLP-DEC-001).
- **R9 is at risk** until the stop chain, now with two contactors in series, has a PL calculation.

## Assumptions

- Rolling resistance 1.2 % and breakaway resistance 2.5 % for polyurethane steer and load wheels on smooth concrete. These are assumptions to be measured on a real jack.
- Tread-to-floor friction coefficient 0.5 for the drive wheels on dusty concrete, 0.4 as a low case; lower on wet or polished floors.
- The drive wheels carry 1.5 kN of spring preload and no share of the pallet load.
- Motor plus driver efficiency 70 %; controls, UWB, scanner and lights draw about 11.3 W in total.
- Stop delays of 0.15 s for the scanner layer and 0.10 s for the bumper and emergency stops.
- R8 is met by the 0.15 m/s speed limit, not by a longer-travel edge; a firmware or hardware fault that lets the truck exceed 0.15 m/s in a bumper-only mode would defeat it.
- The legal status of the retrofit is set by OSHA 1910.178(a)(4) (D8). Follow mode is treated as a driverless truck function under ISO 3691-4 (decided 2026-10-02), the stricter answer that R7 and R9 anticipated. The kit is documented for research use in a closed area (D8).

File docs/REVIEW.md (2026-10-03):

# Review note: PalletPilot

## Session 2026-09-25: /populate to a strong TRL 2

Overnight batch run; no questions were asked. Every choice that is Amish's to make is listed below as proposed.

### What was done

- `docs/01-problem.md` (PLP-PRB-001 v0.2): problem with ergonomic push-force data, users and context, operating environment, constraints (including OSHA 1910.178 training and modification approval, and ISO 3691-4), out of scope, prior work with inline sources, open questions; co-design checklist added in the portfolio's standard form.
- `docs/03-requirements.md` (PLP-REQ-001 v0.2): 17 measurable requirements (R1 to R17) with targets, verification and a status column, a design load case and design duty, and a list of requirements not met.
- `docs/02-concept.md` (PLP-PRC-001 v0.2): how it works, components table numbered to the BOM and exploded view, first-order numbers (forces, traction, stopping, UWB bearing error, energy, mass and cost) with assumptions, key design choices, safety section, open questions.
- `cad/src/concept_media.py`: massing model of a 27 x 48 in donor jack (grey) and 13 numbered kit parts, with a 48 x 40 in pallet and cartons as hero context.
- `media/`: `hero.png`, `concept-blueprint.png`, `.pdf` and `.svg`, `model.glb` and `viewer.html`, `exploded.png` with BOM callouts, `cutaway.png`, `flow.png` (energy per shift, estimates marked).
- `bom/bom.csv`: 17 lines with indicative USD prices, rows 1 to 13 numbered to match the exploded view; `bom/bom-notes.md` updated.
- `README.md`: hero image, links line, updated problem, concept, components and safety.
- `docs/pdf/`: branded PDFs of the three controlled documents.
- `project.yaml`: unchanged. The pitch and problem are still accurate (see decision 1 on the pitch wording).

### Key results (estimates, to be checked at TRL 3)

| Quantity | Estimate | Requirement |
| --- | --- | --- |
| Rolling and breakaway force, 1,100 kg total | about 130 N and 270 N | Motivates the kit |
| Available traction (1.1 kN preload, friction 0.5) | about 550 N | R2 met; R3 (2 % ramp) at risk |
| Stop from 1.2 m/s, walk mode | about 1.56 m | Normal walkie practice |
| Stop from 0.6 m/s, follow mode | about 0.42 m, against about 40 mm bumper travel | R7 **not met** |
| Bumper-only safe speed | about 0.2 m/s | R8 met at that speed |
| UWB bearing error, two anchors 450 mm apart | about ±18° raw | R5 (±10°) **not met** on paper |
| Energy per shift, 60 moves | about 281 Wh of 410 Wh usable | R12 met |
| Charge time | about 4.5 h | R13 met |
| Kit mass | about 37 kg | R15 mass met |
| Added length at floor level | about 330 mm | R15 length (300 mm) **not met** |
| Kit parts cost | about $1,425 | R17 ($1,200) **not met**, about 19 % over |
| Walk-only variant | about $1,075 | Within budget |

Requirements not met or at risk: R7 (non-contact stop in follow mode), R5 (bearing accuracy), R15 (added length, by about 30 mm), R17 (cost) and R3 (2 % ramp, traction margin). R1, R6, R9, R10, R14 and R16 are unverified.

Market context found: a complete 1,500 kg lithium walkie now costs about $1,640 and the PowerPallet 2000 retrofit about $2,084. A walk-only kit plus a new donor jack costs about the same as a new walkie, so PalletPilot's case rests on follow mode and on reusing existing jacks.

### Proposed, awaiting Amish (now decided)

All nine items below: Decided by Amish, 2026-09-25: go with recommendation (PLP-DDR-001, D1 to D9).

1. **Follow-mode stopping and the pitch.** Options: (A) add a low-cost lidar or time-of-flight sensor as the main stopping layer, bumper as last resort, follow mode 0.6 m/s, research use in a closed area; (B) safety-rated laser scanner (over $1,000 on its own); (C) bumper only with follow mode at 0.2 m/s; (D) drop follow mode. Recommendation: A for the prototype, with B named as the route to workplace use. This would change "bumper-based stopping" in the pitch to "layered stopping"; `project.yaml` is unchanged until you decide.
2. **Budget.** Options: (a) raise `budget_usd` from $1,200 to about $1,450 (about $1,550 with option 1A); (b) keep $1,200 and cut to the walk-only variant (about $1,075); (c) keep $1,200 and cut elsewhere (for example a single hub motor plus a steering actuator, cheaper bumper). Recommendation: (a), since follow mode is the reason to build the kit. `project.yaml` is unchanged at $1,200.
3. **Drive layout:** two hub motors on a sprung module on the steering yoke, steering by differential drive in follow mode. Alternatives: one motor plus a steering motor, or load-rated drive wheels replacing the steer wheels. Recommendation: dual hub motors.
4. **Power system:** 24 V LiFePO4, 20 Ah. The SwapCell 48 V pack is not proposed because the kit needs only 24 V and stays on the jack all shift. Recommendation: 24 V LiFePO4.
5. **Mounting:** pack and electronics on the steering yoke, not the forks. Recommendation: yoke mounting, checked for handle clearance and bearing load at TRL 3.
6. **Speeds:** walk 1.2 m/s handle-end first and 0.8 m/s forks first, creep 0.3 m/s, follow 0.6 m/s (0.2 m/s until option 1 is built and tested).
7. **Kit rating:** 1,000 kg design load, 1,500 kg maximum at 0.8 m/s or less, below the donor's 2,500 kg.
8. **Legal route for workplace use** (OSHA 1910.178(a)(4) needs the jack maker's written approval for modifications affecting capacity and safe operation). Options: partner with a jack maker for one donor model; document the kit for research and non-workplace use only; or both. Recommendation: document for research use now, and approach a jack maker before any workplace trial.
9. **First site partners:** a small warehouse or 3PL, a grocery or retail backroom, or a maker space. Recommendation: one small warehouse and one maker space.

### Safety concerns

- A loaded jack in follow mode will strike a person before a bumper can stop it at any speed above about 0.2 m/s. This is the main safety finding and drives decision 1.
- Foot crush and pinning at the drive end are the classic walkie injuries; the belly-reverse paddle, handle-angle braking and bumper hoop address them but are unverified.
- Braking falls by about 40 % on a 2 % downgrade; ramps and dock plates need limits.
- The 512 Wh LiFePO4 pack needs a BMS, a terminal fuse, a lockable disconnect and safe charging practice.
- Workplace use raises OSHA training and modification-approval duties; the kit must be presented as a research prototype.

### Gaps against the brief

- The OSHA page could not be fetched during the session (the permission request timed out); the 1910.178 citations use the official regulation URL and a secondary summary for the training requirement. The wording of 1910.178(a)(4) should be checked against the source.
- Hub motor torque, brake holding torque and prices are for the part class, not a chosen supplier.

### Recommended next step

Review this note and the media, and decide items 1 and 2. If approved, run `/advance-trl3` to size traction, braking and the stop chain by calculation, choose the motors and the follow-mode sensor, build the UWB error budget, and produce the parametric model and drawing sheet.

## Session 2026-09-25: TRL 3

Amish's instruction for this session (2026-09-25): "proceed with all of your recommendations across all batches. Make sure we don't proceed to TRL 4 on any of them." For PalletPilot the approved safety recommendation is the low-cost lidar or time-of-flight stop layer (option 1A), the approved budget is about $1,550, and the pitch changes to "layered stopping". PalletPilot now claims TRL 3 (proof of concept on paper). TRL 4 is on hold by Amish's instruction.

### What was done

- `docs/decisions/0001-trl2-review-decisions.md` (PLP-DDR-001 v0.1): nine TRL 2 items recorded as decided by Amish, 2026-09-25, going with the recommendation (D1 to D9), and six items that stay open (O1 to O6).
- `docs/04-calcs/01-sizing.md` (PLP-CAL-001 v0.1) and `docs/04-calcs/sizing.py`: mass, axle and bearing loads, traction and preload, motor torque and power, steering by differential drive, layered stopping (lidar, bumper, emergency stop, tag loss, parking), protective field sizing, UWB error budget, energy and charging, handle clearance, length, release lever, cost, and a status line for every requirement. The script imports the model's `PARAMS` and the BOM, and prints every number the note quotes, tagged [B0] to [R0].
- `cad/src/model.py`: parametric build123d model (donor jack as reference; subframe with yoke clamp, hub motors, enclosure and lid, pack, driver, contactor, controller, tiller head, beacon, emergency stops, bumper hoop, UWB anchors, release lever, lidar and bracket) with `PARAMS` and `derived()`. Exports `cad/step/` and `cad/stl/`: `palletpilot-assembly`, `palletpilot-kit`, `drive-module`, `enclosure`, `bumper-and-sensors` and `tiller-head`.
- `cad/src/sheets.py` and `cad/drawings/PLP-DWG-001.svg`, `.pdf`, `.png`: general arrangement at Rev P1, scale 1:20, with length at floor level, added length, steer axis to drive axle, overall height, pivot height, width, bumper width, anchor baseline and drive track drawn from the model, an isometric view and a dimensions box. It carries "CONCEPT, NOT FOR FABRICATION" and "PRELIMINARY, NOT FOR FABRICATION". The concept sheet is PLP-DWG-010, so DWG-001 was free.
- `bom/bom.csv` and `bom/bom-notes.md`: all 18 lines priced with a supplier or supplier type; new line 18 (obstacle lidar); motor spec raised to 30 N·m peak; two lines checked against live listings.
- `cad/src/concept_media.py` now builds the media from `model.py`, with key figures and flow values from PLP-CAL-001. Every image in `media/` was regenerated and checked by eye (exploded callouts reordered by BOM number); the temporary `media/_views*` and `cad/drawings/_views` folders were deleted.
- PLP-PRB-001, PLP-PRC-001 and PLP-REQ-001 revised to v0.3; `README.md` updated (TRL 3, layered stopping, $1,550, links); `project.yaml` set to `trl: 3`, `trl_target: 3`, `budget_usd: 1550`, new pitch, evidence listed. PDFs are in `docs/pdf/`.

### Requirements (PLP-CAL-001, Table 5)

9 met, 3 not met, 3 at risk, 3 not verifiable at TRL 3 (R15 counted as two lines, mass and length).

| ID | Status | Value against target |
| --- | --- | --- |
| R5 | **Not met** | Bearing about ±16° (2σ) after filtering against ±10°; ±10° would need a 706 mm anchor baseline, wider than the 685 mm jack. Gap ±0.06 m is fine |
| R15 mass | **Not met** | 41.7 kg against 40 kg; the 30 N·m motors weigh about 7 kg each |
| R17 | **Not met** | $1,580 against $1,550 ($30, 1.9 %); within motor pricing uncertainty |
| R7 | At risk | Lidar stop 0.42 m level, 0.76 m worst case, inside a 0.86 m field that stays 0.19 m clear of the operator; sensor not safety-rated |
| R8 | At risk | Chain acts in 0.10 s, but 0.2 m/s needs 62 mm of edge travel against 40 mm; 0.15 m/s fits |
| R9 | At risk | Single contactor output; PL d not calculated |
| R1 | Not verifiable at TRL 3 | Needs a donor survey |
| R6 | Not verifiable at TRL 3 | Timing budget 0.20 s against 0.3 s; no firmware |
| R16 | Not verifiable at TRL 3 | Set by bought-part specifications |
| R2, R3, R4, R10, R11, R12, R13, R14, R15 length | Met | 25.5 of 30 N·m; ramp margin 1.54; brakes 40 against 21.7 N·m; handle clearance 40 mm at 70°; 292 of 410 Wh; 4.5 h charge; +3.9 % push force; 290 mm added length |

Other key numbers: traction 750 N at 1.5 kN preload; peak 554 W and 31 A; emergency stop from 1.2 m/s 1.62 m level and 2.66 m on a 2 % downgrade; wall energy 350 Wh per shift.

Design changes made while sizing, within the decided configuration: preload raised from 1.1 to 1.5 kN (R3 was at risk); motor spec raised to 30 N·m peak (the TRL 2 class was too weak); enclosure lowered below the handle pivot (the TRL 2 layout would have hit the handle at about 51°) with the beacon moved to the tiller head and the second emergency stop to the enclosure's rear; drive axle moved 40 mm closer and the track widened to 260 mm (R15 length now met); lidar placed inside the bumper face with its scan plane at 200 mm. Every TRL 2 number in the docs was checked against the script and corrected (PLP-CAL-001, Table 6). TRL 2 overstated the bumper-only safe speed (0.2 m/s; it is 0.15 m/s).

Other findings: the motors cannot swing the yoke at standstill (98 N·m available against 135 N·m of scrub), so follow mode must steer only while rolling, and standstill hand steering gets about 112 N heavier at the grip. The 1,500 kg rating holds on level floors only (a ramp start needs 35.4 N·m per motor).

### Decisions recorded (PLP-DDR-001)

Decided by Amish, 2026-09-25, going with the recommendation: D1 layered stopping with a low-cost lidar layer, bumper last, follow 0.6 m/s, research use in a closed area, safety-rated scanner named for workplace use, pitch "layered stopping"; D2 budget $1,550; D3 dual hub motors on a sprung yoke module; D4 24 V LiFePO4 20 Ah, not SwapCell; D5 everything on the yoke; D6 speeds 1.2, 0.8, 0.3 and 0.6 m/s (follow 0.2 m/s until the lidar layer is tested); D7 1,000 kg design load, 1,500 kg at 0.8 m/s or less; D8 research use now and a jack maker's written approval before any workplace trial; D9 partner types, one small warehouse and one maker space. `budget_usd` is now 1550 and the pitch is reworded in `project.yaml` and `README.md`; the problem line is unchanged (no rewording was recommended). The SwapCell interface decisions do not apply, since PalletPilot has its own pack.

### Proposed, awaiting Amish (items 4 to 6 now decided)

1. Named site and co-design partners (O1); partners are picked per area later.
2. Follow-mode classification under ISO 3691-4 (O2). No recommendation.
3. Donor models to support first (O3). No recommendation.
4. Bumper-only stopping (O4, R8): (a) limit bumper-only speed to 0.15 m/s, or (b) an edge with 65 mm or more of travel (adds about 25 mm of length, to about 315 mm, over the 300 mm in R15). Recommendation: (a), since the lidar is the primary layer in follow mode. **Decided by Amish, 2026-09-25: go with recommendation** (PLP-DDR-002).
5. Overruns (O5): cost $30 over and mass 1.7 kg over. Options: accept both as within estimate uncertainty and recheck when a motor is quoted; choose a lighter motor with published torque; or raise the budget to $1,600. Recommendation: accept for now and recheck at the motor quote, with no budget change. R5: angle-of-arrival UWB or lidar leg tracking; recommendation: evaluate both at TRL 4, when allowed. **Decided by Amish, 2026-09-25: go with recommendation** (PLP-DDR-002; the R5 evaluation is on hold with TRL 4).
6. Stop chain (O6, R9): add a second contactor or a driver with rated safe torque off (about $30). Recommendation: add the second contactor, which would push cost to about $1,610. **Decided by Amish, 2026-09-25: go with recommendation** (PLP-DDR-002).

### Safety concerns

- The lidar layer is not safety-rated; its range on black targets falls to 6 m and detection of dark clothing at shin height is unproven. Follow mode stays at 0.2 m/s or less in a closed area with no bystanders until tested.
- A 40 mm safety edge stops the loaded truck only from 0.15 m/s or less.
- Emergency braking on a 2 % downgrade needs 2.7 m from 1.2 m/s; no 1,500 kg loads on ramps.
- The 512 Wh LiFePO4 pack needs its BMS, terminal fuse, lockable disconnect and safe charging practice.
- The drive adds up to 750 N of horizontal load at the donor's steering bearing; worn jacks must not be converted.
- Workplace use needs the jack maker's written approval under 29 CFR 1910.178(a)(4) and trained operators.

### Citations

The 1910.178(a)(4) and (l)(1)(i) wording was checked against the OSHA page in this session and now appears as a quotation in PLP-PRB-001. The motor and lidar prices were checked against the listings cited in `bom/bom-notes.md`. No unchecked citation flags remain.

### Gaps against the brief

- Hub motor mass, brake torque and 24 V availability are for the part class, not a quoted motor; R10 and the mass figure rest on the specified minimums.
- No TRL 4 material exists in the repo; `build-log/README.md` is the scaffold file only.

### Recommended next step

TRL 4 is on hold by Amish's instruction. Next, decide items 4 to 6 above, then run a paper follow-up at TRL 3: a donor survey from published jack drawings (yoke geometry, pivot height), a motor quote with brake data, and a PL estimate of the stop chain. For reference only, TRL 4 would need: a bench build of the drive module on one donor jack, measured rolling resistance, friction and stopping distances, lidar detection tests with dark clothing and a test piece, UWB bearing trials, a stop-chain test, a TST report with `environment: lab`, and build log entries.

## Session 2026-09-25: recommendations accepted

Amish wrote on 2026-09-25: "i accept all your recommendations, go with them across all repos." Every open item with a recommendation is now decided in favor of it and recorded in `docs/decisions/0002-recommendations-accepted.md` (PLP-DDR-002). Items without a recommendation stay open. TRL stays at 3.

### Decisions applied and what changed

| Item | Decision | Before | After |
| --- | --- | --- | --- |
| O4, bumper-only stopping (R8) | Option (a): bumper-only speed limit 0.15 m/s; follow mode also 0.15 m/s until the lidar layer is tested | Limit 0.2 m/s, 62 mm stop against 40 mm travel, R8 at risk; interim follow 0.2 m/s | Limit 0.15 m/s, 38 mm stop, R8 met on paper; interim follow 0.15 m/s |
| O5, overruns and R5 | Accept the mass and cost overruns for now, recheck at a motor quote, no budget change; evaluate angle-of-arrival UWB and lidar leg tracking at TRL 4 (on hold) | Budget $1,550 | Budget $1,550 (unchanged); R5 evaluation on hold. Cost overrun decided by Amish, 2026-09-26: budget set to $1,610 (PLP-DDR-002 v0.2) |
| O6, stop chain (R9) | Add a second main contactor in series, one per safety relay channel | One contactor; BOM line 6 $45; BOM $1,580; kit 41.7 kg | Two contactors; line 6 $75; BOM $1,610 (3.9 % over); kit 42.0 kg |

Files changed: `docs/04-calcs/sizing.py` and PLP-CAL-001 v0.2 (stop table, [S3], requirement table, mass, cost); PLP-REQ-001 v0.4 (R4, R8, R9 restated; status); PLP-PRC-001 v0.4 (components, key numbers, design choices, safety); PLP-DDR-001 v0.2 (O4 to O6 marked decided); new PLP-DDR-002 v0.1; `bom/bom.csv` line 6 and `bom/bom-notes.md`; `cad/src/model.py` (two contactors) with STEP and STL re-exported; `cad/src/sheets.py` and PLP-DWG-001 to Rev P2; `cad/src/concept_media.py` key figures and flow (pack 292 to 293 Wh) with all media regenerated; `README.md`; `project.yaml` (DDR-002 added as evidence; budget, pitch and problem unchanged). Small knock-on changes: push-force rise 3.9 % to 4.0 %, yoke load at 1,500 kg 6.80 to 6.81 kN.

The README gained the sections Concept rationale, Burning platform, Where it could be used and What sparked the idea. All docs PDFs, the drawing and the media were regenerated with the designmolecule.com footer.

### Requirement status (PLP-CAL-001 v0.2)

10 met, 3 not met, 2 at risk, 3 not verifiable at TRL 3 (was 9, 3, 3, 3).

| ID | Status | Value against target |
| --- | --- | --- |
| R5 | **Not met** | Bearing ±16° (2σ) against ±10°; fixes evaluated at TRL 4, on hold |
| R15 mass | **Not met** | 42.0 kg against 40 kg; accepted for now |
| R17 | **Not met** | $1,610 against $1,550 ($60, 3.9 %); accepted for now |
| R7 | At risk | Lidar stop 0.42 to 0.76 m inside a 0.86 m field; sensor not safety-rated |
| R9 | At risk | Two contactors in series; PL not calculated |
| R1, R6, R16 | Not verifiable at TRL 3 | Donor survey, firmware, bought-part specifications |
| R2, R3, R4, R8, R10, R11, R12, R13, R14, R15 length | Met | R8 now met: 0.15 m/s stops in 38 mm of 40 mm travel |

### Still awaiting Amish

- O1: named site and co-design partners (picked per area later).
- O2: classification of follow mode under ISO 3691-4. No recommendation.
- O3: donor jack models to support first. No recommendation.

### Cross-repo actions

None. PalletPilot has its own 24 V pack and no interface with another repo.

### Safety

- R8 now rests on a speed limit, so the 0.15 m/s cap in bumper-only operation and in untested follow mode must be enforced by the controller and checked in any later firmware review.
- The two-contactor chain still needs a PL calculation before any claim toward PL d.
- The other safety concerns in the TRL 3 session stand.

### TRL 4

TRL 4 remains on hold by Amish's instruction. No build, test, purchase, PCB or firmware work was done.

### Recommended next step

Decide O2 and O3. Paper work that remains at TRL 3: a motor quote with brake data to recheck the mass and cost overruns, a PL estimate of the two-contactor stop chain, and a donor survey from published jack drawings.

## Session 2026-09-26: sources strengthened

Amish asked on 2026-09-26 to fix the weaker sources in the README. Changes (README only; no controlled document changed):

- What sparked the idea: VentureBeat replaced by Piaggio Fast Forward's own press release of October 15, 2019 (GlobeNewswire), which gives the $3,250 price, the November 18, 2019 sale date, 6 mph and 40 lb. The wording now says "visual sensors", as the release does. The easyPILOT Follow mention now links Jungheinrich's press release. INSPIRATIONS.md line updated to the new source.
- By country or region: Japan now cites the Statistics Bureau of Japan (29.3 % aged 65 or over, October 1, 2024). India and Brazil were rewritten to state their World Bank Logistics Performance Index 2023 scores (3.4 and 3.2), the only claim the source supports. Kenya and East Africa was replaced by South Africa (LPI 2023 score 3.7), because no Kenya figure could be verified in the LPI 2023 table.
- United States: OSHA 1910.178 now carries a link to the standard.
- Kept and rechecked: BLS warehousing rate (4.8, 2024), BLS private industry rate (2.3, 2024), EU-OSHA MSD figures.

## Session 2026-09-26: budget approved

On 2026-09-26 Amish wrote: "i approve all the budget items." The cost overrun accepted for now under O5 is decided: budget set to $1,610 to cover the priced BOM, recorded in PLP-DDR-002 v0.2.

- `project.yaml`: `budget_usd` 1550 to 1610. The priced BOM is exactly $1,610 over 18 lines, so the figure covers it with no margin.
- R17: **not met** ($60 over $1,550, accepted for now) to **met**. Requirement status is now 11 met, 2 not met (R5, R15 mass), 2 at risk and 3 not verifiable.
- `docs/04-calcs/sizing.py` now checks against $1,610 and was rerun; PLP-CAL-001 v0.3, PLP-REQ-001 v0.5, PLP-PRC-001 v0.5, PLP-PRB-001 v0.4, `README.md` and `bom/bom-notes.md` quote the new figure. The concept blueprint quotes the kit cost only, so `media/` was not regenerated.
- The motor quote remains the next paper check for the R15 mass overrun and for R17, which has no cost margin left. O1 to O3 are still awaiting Amish.

## Session 2026-09-26: product appearance model and photoreal renders

Amish chose this repo for the first batch of product renders on 2026-09-26. This session added `cad/src/product_model.py`, an appearance model for photoreal renders, and pointed the README hero image at `media/render-hero.png` with a link to `media/render-exploded.png`. The render files are produced separately.

### What product_model.py adds

- `product_parts()`, `TITLE` and three `RENDER_VIEWS`: hero (kit on the loaded jack with the operator), exploded, and a detail view of the drive end without context.
- Drive module: filleted subframe plate, trailing cheeks with rounded ends, bolt heads and axle nuts, coil preload springs on their seats.
- Hub motors: grooved tyres, machined hub faces with face bolts, cable exits.
- Enclosure: filleted teal body with side louvers and a lid gasket line, a charcoal lid frame with a clear polycarbonate window over the pack, BMS, driver, contactors, controller and safety relay (lit status light), lid screws, cable glands, name plate and battery warning label, the rear emergency stop on its yellow plate, and the red disconnect knob.
- Contact bumper split into a yellow steel hoop and a black safety edge with marking; white UWB anchor radomes on the corners; lidar puck with base, scan window and cap on its bracket; manual release lever with a red grip.
- Tiller head: body, rubber grips with end caps, thumbwheel throttles, belly-reverse paddle, key switch, horn button, emergency stop, UWB anchor and an amber beacon lit for walk mode; spiral-wrapped cable from a lid gland up the handle.
- Context: the donor jack, a 48 x 40 in stringer pallet with cartons, and the shared clay mannequin in a push pose holding the grips, with a belt and the operator UWB tag.

### Differences from model.py

Each is Proposed, awaiting Amish. No controlled document or model.py dimension was changed.

1. **Handle angle.** The renders show the handle at 40 degrees from vertical (mid walk band); model.py shows 20 degrees, the upright edge of the band. At 20 degrees the grips would sit at about 1.24 m, above a natural hand height for a 1.75 m operator. Recommendation: accept 40 degrees for renders only and leave model.py at 20 degrees.
2. **Tiller head width.** The grips span 248 mm over their end caps against the 220 mm `head_w`, so two hands fit beside the head body. Recommendation: accept for renders and revisit `head_w` when a tiller head is chosen.
3. **Tiller UWB anchor position.** The anchor radome sits under the left grip on the head body instead of 35 mm outboard of the head, where the grips now are. Recommendation: accept; the anchor stays on the head as the concept requires.
4. **Parts not modelled in model.py.** The operator tag (BOM 15) and the spiral-wrapped tiller cable (BOM 17) are shown for the renders. Recommendation: keep them in the appearance model only.

### TRL

This is an appearance model only: no tolerances, fabrication detail, PCB layout or firmware. `trl` stays 3 and TRL 4 remains on hold by Amish's instruction.

## Session 2026-09-27: kit 1.5.0 and image quality

- Kit 1.5.0 synced: STANDARDS v1.5 (sections 12 to 15: product renders, storefront images and image quality, public release, authorship and signing), `.kit/cards.py`, `.kit/image_qc.py`, `.kit/release_gate.py`, issue templates, and the `/render-product` and `/release` commands. `CLAUDE.md` now matches `.kit/CLAUDE.md`.
- Every `media/render-*.png` recaptioned from its original render with the new layout: the title, concept label and repository sit in a band above the render and the view note in a band below it, each line wrapped to the image width, so no text overlaps other text or the render or runs off the image. `media/card.png` and `media/social-preview.png` regenerated with the same rules.
- `python .kit/image_qc.py` and `python .kit/release_gate.py` pass. trl stays 3.

## Session 2026-10-01: kit 1.7.0, constructable design and prototype build plan

Kit 1.7.0 installed (`.kit/`, `.claude/commands/`, `CLAUDE.md`). Following `.claude/commands/build-plan.md` and STANDARDS section 18, the model was checked for constructability with build123d and made buildable under Amish's 2026-09-30 instruction ("If you are realising that the design cannot be built as per concept - fix the design assumptions to match and be physically feasible as you draw the illustrations."). No git commit or push was made in this copy.

### Design changes made for construction (PLP-DDR-003, Draft, open for Amish's review)

- **Yoke clamp.** The 20 mm slab and loose tongue became a 6 mm top plate resting on the yoke plate with a 62 mm notch round the pump, and a 10 mm lower jaw with a packing bar; four M12 bolts behind the yoke's edge grip the yoke plate. Nothing is drilled in the jack (R1).
- **Sprung drive arms.** The welded trailing cheeks and floating spring towers became two 10 mm drive arms on a 20 mm pivot pin in rear hangers behind the wheels, each pushed down by a 100 N/mm spring at its front end (arm ratio 1.77; 423 N per spring gives 750 N per wheel).
- **Hub motor mounting.** Each motor's shaft passes through its arm with a 5 mm spacer and a nut.
- **Manual release.** The unconnected lever became a 16 mm cam shaft in front hangers with two 22 mm eccentric cams, a crank, a link and a 400 mm over-center lever on a bracket with a stop (a parallelogram). Raising the lever lifts the saddles 22 mm and, through slotted straps, the drive wheels 10 mm clear; peak effort about 58 N (was estimated at 117 N).
- **Bumper.** The solid block mounted on the moving cheeks became a 40 x 20 x 2 tube hoop bolted into rivet nuts on brackets welded under the top plate, with the safety edge on the front (50 mm deep, 40 mm travel) and both sides; side legs shortened to start 120 mm behind the steering axis.
- **Lidar and anchors.** Lidar on a bent strap bracket on the hoop; the two anchors on corner plates on the hoop, tops at 180 mm, below the 200 mm scan plane.
- **Enclosure.** Four riveted angle feet bolted to the top plate; holes for the rear stop and the disconnect; box 89 mm plus a 6 mm lid (95 mm as before).
- **Steering.** The kit's drive end reaches the jack's frame head at about 44° of turn on the reference donor (the top plate corners at 34°). Top plate corners cut back 50 mm and two rubber steering stops (new BOM line 19) meet the frame at 40° each way.
- **Donor reference geometry** corrected so the donor's own parts no longer overlap (yoke plate above the steer wheels, frame head 100 mm ahead of the steering axis).

`python cad/src/model.py --check` passes: 36 components, no overlaps, all 46 contacts touch, no collision with the lever raised, and the stops meet the frame before any other kit part.

### Results and numbers

- Kit mass 44.4 kg (was 42.0 kg); R15 mass not met by 4.4 kg.
- Value-engineering target: USD 1,610. Estimated cost of the constructable design: USD 1,690 (USD 80 over the target); lines 1, 3 and 13 repriced, line 19 added.
- PLP-CAL-001 v0.4 rerun: worst motor torque 25.6 N·m of 30; ramp margin 1.53; bumper-only stop 39 mm of 40 mm; 28 % of usable energy left; release effort 58 N; steering range [G5]. Requirement status unchanged: 10 met, 2 not met (R5, R15 mass), 2 at risk (R7, R9), 3 not verifiable (R1, R6, R16); R17 is reported against the target.
- Documents: PLP-BLD-001 v0.1 (`docs/05-build-plan.md`, new), PLP-DEC-001 v0.1 (`docs/06-design-decisions.md`, new), PLP-DDR-003 v0.1 (new), PLP-CAL-001 v0.4, PLP-REQ-001 v0.6, PLP-PRC-001 v0.6, `bom/bom.csv`, `bom/bom-notes.md`, `README.md` (links line and "Building the prototype"), `project.yaml` (`design_state: constructable`, evidence).
- Drawings and pictures: PLP-DWG-001 Rev P4; making sketches PLP-DWG-101 to 111 (11); 10 joint close-ups; 15 step pictures; overview; block-level wiring; concept media (PLP-DWG-010 Rev P2) and STEP/STL regenerated from the model. Pictures come from `cad/src/build_plan_media.py`.

### Proposed, awaiting Amish (in PLP-DEC-001)

1. Steering range of about 40° each way with the kit fitted, against about 90° bare; the precis no longer says the kit steers like the bare jack. Recommendation: accept for the prototype and measure the turning circle at TRL 4.
2. Kit mass 44.4 kg against 40 kg. Recommendation: accept for the prototype, recheck at the motor quote.
3. Wheel lift of 10 mm with the release raised. Recommendation: accept for smooth indoor floors.
4. to 6. Still open from PLP-DDR-001: ISO 3691-4 classification (O2), donor models (O3), named partners (O1).

### Stale until regenerated on Amish's Mac

The photoreal renders (`media/render-hero.png`, `media/render-exploded.png`, `media/render-detail.png`; not present in this cloud copy, made on Amish's Mac), `media/card.png` and `media/social-preview.png`, and the appearance model `cad/src/product_model.py`, still show the concept's trailing cheeks, spring towers, solid bumper block and unlinked release lever. The design changed visibly (sprung arms, tube hoop, cam-and-link release, clamp jaw), so all of them are stale.

### Safety

The build plan carries eight safety stops (battery handling, first power with the wheels lifted, stop-chain checks before the motors turn, cordoned area, no follow mode until the lidar layer is tested, charging). The welds on the hangers and hoop carry the drive and spring loads and need a competent welder. The steering stops prevent steel-on-steel contact with the jack frame at full turn.

### Recommended next step

Amish to review PLP-DDR-003 and decide open decisions 1 to 3 in PLP-DEC-001; then the donor survey (O3), which sets the packing bar, clamp, notch and stop angle. TRL 4 stays on hold.

## Session 2026-10-01: steering range decided

Amish, 2026-10-01: "i accept your recommendations for PalletPilot". He was shown the recommendation for open decision 1 of the design decisions register (PLP-DEC-001 v0.1), the steering range, so only that item (PLP-DDR-003, A1) is decided. The kit mass (A2), the wheel lift (A3), the Table 1 changes of PLP-DDR-003 and the other open items stay open. No design change; trl stays 3; no build or test work was done.

### Accepted, as recommended

| Register item (v0.1) | Decision |
| --- | --- |
| 1 | Steering range, option (a): accept about 40° each way with the kit fitted for the prototype; set the rubber stops from the donor survey; correct the wording so the kit no longer claims to steer like the bare jack. **Go or no-go gate:** the TRL 4 aisle test must show the kit can make a right-angle turn into a standard pallet bay; if it cannot, the drive layout changes before TRL 5 (option c, for example one centre drive wheel under the yoke, which reopens D3) |

### What changed

- `docs/06-design-decisions.md` (PLP-DEC-001 v0.2): item 1 moved to Decisions made, dated 2026-10-01, with Amish's words, the go or no-go gate and the record (PLP-DDR-003, A1); open items renumbered 1 to 5.
- `docs/decisions/0003-design-for-construction.md` (PLP-DDR-003 v0.2): status line records that A1 is decided with Amish's words, and that Table 1, A2 and A3 stay open; Table 3 marks A1 accepted, with the gate added to its recommendation; a consequence states the range and the gate.
- Steering wording: the range is now stated plainly as about 40° each way with the kit fitted, set by rubber stops (about 90° for a bare jack), a turning radius of roughly 1.5 m about the load wheels, confirmed in the TRL 4 aisle test.
  - `README.md`: walk-mode paragraph.
  - `docs/02-concept.md` (PLP-PRC-001 v0.7): summary (no longer points at an open decision) and walk mode, which said only that "the handle steers freely".
  - `docs/03-requirements.md` (PLP-REQ-001 v0.7): no requirement covers manoeuvrability, so none was added or restated; a TRL 4 verification note for the steering range sits with the requirements not met or at risk, with the aisle test as its pass criterion and gate.
  - `docs/05-build-plan.md` (PLP-BLD-001 v0.2): section 3.2 (steering stops) states the range and radius; Table 3 (first checks) gains an "Aisle turn" check; references to PLP-CAL-001 v0.5 and PLP-REQ-001 v0.7.
  - `docs/04-calcs/01-sizing.md` (PLP-CAL-001 v0.5): the steering paragraph called the range "open decision 1"; it now records the decision, the radius and its basis (load rollers 1,130 mm from the steering axis on the reference donor). No number changed; the script was not rerun.
- `project.yaml` pitch, `CITATION.cff` and `docs/01-problem.md` were checked: none claims the kit steers like the bare jack (the pitch is "Retrofit kit that turns a manual pallet jack into a powered, walk-behind unit..."), so they are unchanged. The bare-jack claim survives only as history in PLP-DDR-003 and the register's decision text.
- PDFs regenerated with `python3 .kit/render.py`.

The roughly 1.5 m radius is a plain-geometry estimate: with 40° of steer and the load rollers 1,130 mm behind the steering axis, the turning centre lies about 1.35 m to the side of the load-roller midpoint, and the outer load wheel runs at about 1.6 m. Requirement status is unchanged: 10 met, 2 not met (R5, R15 mass), 2 at risk (R7, R9), 3 not verifiable at TRL 3 (R1, R6, R16); R17 USD 80 over its value-engineering target.

### Still open (PLP-DEC-001)

1. Kit mass of 44.4 kg against 40 kg (A2).
2. Drive wheel lift of 10 mm (A3).
3. Classification of follow mode under ISO 3691-4.
4. Donor jack models and steering yokes to support first.
5. Named site and co-design partners.

Acceptance of the PLP-DDR-003 Table 1 changes is also still open.

### Safety

Unchanged. The rubber stops keep steel parts of the kit off the jack's frame at full turn. Operators used to a bare jack will find the wider turn; the aisle test runs at creep speed in the cordoned test area.

### Recommended next step

Amish decides A2, A3 and the Table 1 changes of PLP-DDR-003; then the donor survey (O3), which sets the stop angle, packing bar, clamp and notch. At TRL 4 the aisle test is the first go or no-go gate: **if the kit cannot make a right-angle turn into a standard pallet bay, change the drive layout (option c, for example one centre drive wheel under the yoke, reopening D3) before TRL 5.** TRL 4 stays on hold.

## Session 2026-10-02: open decisions decided

Amish approved every recommendation for the open decisions on 2026-10-02: "i approve your recommendations for all 555 open decisions."

### Decisions recorded

Five, all moved to "Decisions made" in PLP-DEC-001 (open items 1 to 5): kit mass of 44.4 kg accepted for the prototype with R15's prototype limit restated as 45 kg and about 1.5 kg of savings carried into the TRL 4 drawings (PLP-DDR-003, A2); 10 mm drive wheel lift for smooth indoor floors only (PLP-DDR-003, A3); follow mode treated as a driverless truck function under ISO 3691-4; a donor survey of three widely sold jacks (a Crown PTH 50 series class model, a distributor's standard model such as Uline's, the Harbor Freight Pittsburgh 5,500 lb jack); Dallas Makerspace and a small food bank or charity warehouse in the Dallas and Fort Worth area as the first candidate partners to approach.

### Documents changed

- `docs/06-design-decisions.md` PLP-DEC-001 v0.3: decisions made; open decisions section now reads "None"; To confirm item 1 and the value engineering note updated.
- `docs/decisions/0003-design-for-construction.md` PLP-DDR-003 v0.3: A2 and A3 accepted (status Draft kept); the Table 1 changes stayed open until Amish accepted them later on 2026-10-02 (see the next session).
- `docs/03-requirements.md` PLP-REQ-001 v0.8: R15 restated with a 45 kg prototype limit (now met for the prototype); R7 tied to ISO 3691-4; summary counts.
- `docs/04-calcs/01-sizing.md` PLP-CAL-001 v0.6: R15a status and totals; no figures changed.
- `docs/01-problem.md` PLP-PRB-001 v0.5 and `docs/02-concept.md` PLP-PRC-001 v0.8: follow mode classification, donor survey, first candidate partners, R15 and the wheel lift.
- `docs/05-build-plan.md` PLP-BLD-001 v0.3: the release is for smooth indoor floors only; safety stop S7 treats follow mode under ISO 3691-4.
- `README.md`: Safety note states the ISO 3691-4 treatment of follow mode.

### Follow-up actions to carry approved decisions into the design

1. Decision 1 (calculations): set R15a's prototype limit to 45 kg in `docs/04-calcs/sizing.py` so that its printed status matches PLP-CAL-001.
2. Decision 1 (model, drawings): carry the 5 mm top plate, tube lever and hollow pivot pin (about 1.5 kg) into the model and the TRL 4 drawings.
3. Decision 3 (BOM, calculations): choose a safety-rated personnel detection sensor and define the stopping functions to ISO 3691-4; re-specify the lidar line and rerun the R7 stopping case for it.
4. Decision 4 (model, drawings): after the donor survey, set the packing bar thickness, clamp holes, notch and steering stop angle for the three surveyed jacks.

### Points found in the review

- The design for construction changes P1 to P10 (DDR-003, Table 1) were still open for Amish's review, with no row in the register for accepting them; the recommendation was to accept. Amish accepted them later on 2026-10-02 (see the next session).
- R15: the register said "2.0 kg over was accepted for now", but the kit is now 4.4 kg over; the accepted figure was out of date (now superseded by the 45 kg prototype limit).
- Cost is $1,690 against the $1,610 target, $80 over, all of it from parts added for construction.

## Session 2026-10-02: design-for-construction changes accepted

Amish, 2026-10-02: "APPROVED: Design-for-construction changes in 10 repos (CityTwin, CoolShade, PalletPilot, Heliolite, PotholeLog, EarthPress, ReadyKit, CellCheck, CargoMule and ThermaCart)". This accepts the design-for-construction changes P1 to P10 in Table 1 of PLP-DDR-003, which were left open for his review when the open decisions were decided earlier the same day. No other item is decided by it. trl stays 3; no build or test work was done, and the model, BOM, calculations and pictures are unchanged.

### Documents changed

- `docs/decisions/0003-design-for-construction.md` (PLP-DDR-003 v0.4, status Draft): status line now "accepted" with Amish's words.
- `docs/06-design-decisions.md` (PLP-DEC-001 v0.4): Decisions made row added, dated 2026-10-02; the 2026-09-30 row no longer calls the record open for review.
- `docs/05-build-plan.md` (PLP-BLD-001 v0.4): section 2 says the Table 1 changes are accepted.
- PDFs regenerated.

### Recommended next step

No change: the follow-up actions of the previous session stand. TRL 4 remains on hold by Amish's instruction.

## Session 2026-10-02: approved follow-ups carried out

Amish approved every follow-up action of the open-decision sign-off on 2026-10-02 ("APPROVED CHANGES, COMPLETE THESE"). Four follow-ups were listed above; results:

### Approved follow-ups carried out

1. Calculations, R15a limit: done. `docs/04-calcs/sizing.py` restates R15a to a 45 kg prototype limit (status Met at 42.9 kg).
2. Model and drawings, 5 mm top plate, tube lever, hollow pivot: done. The top plate is 5 mm, the lever a 20 x 10 x 2 mm tube, and the single pin is two hollow 20 mm pivot tubes (one per arm; this also frees the middle of the frame for the scanner). Kit mass is 42.9 kg (was 44.4 kg). The enclosure is 1 mm deeper (96 mm) because the plate is thinner. STEP and STL regenerated; constructability checks pass (0 overlaps, 46 contacts, nine new clearance checks).
3. Safety-rated personnel sensor and ISO 3691-4 stopping: done on paper. BOM line 18 is now a SICK nanoScan3 Core I/O class scanner (USD 3,444.30 listed, plus about USD 11 for a 3 mm shelf; USD 3,455 for the line). Stopping function defined: scanner safety outputs to the safety relay, monitored controlled stop (stop category 1) by the driver, brakes close at standstill; the driver specification now includes safe torque off. R7 case rerun: controlled stop 0.36 to 0.70 m inside a 0.80 m field (delay 0.15 s). Not resolved: if the drive's controlled stop fails and only the brakes act, the 1,500 kg 2 % downgrade case needs 1.15 m, beyond the field; R7 stays At risk. The scan plane is now 173 mm (was 200 mm), the safety edge 68 mm high and the anchors 165 mm tall, all to make the scanner fit.
4. Donor survey dimensions (packing bar, clamp holes, notch, stop angle): not done. They need the dimensioned drawings of the three surveyed jacks, which are not in the repo; the model keeps the reference donor. This is survey work for the donor jacks, listed under "To confirm when parts are bought" in PLP-DEC-001.

Done 3 of 4.

### Key results

- Requirement changes: none. 11 met, 1 not met (R5), 2 at risk (R7, R9), 3 not verifiable at TRL 3. R15 kit mass 42.9 kg (met for the prototype; 2.9 kg over the 40 kg goal). R12 reserve 24 % (was 28 %, scanner draws about 2 W more). R17: Value-engineering target: USD 1,610. Estimated cost of the constructable design: USD 5,065 (USD 3,455 over the target). `budget_usd` unchanged.
- Cost saving worth trying: a cheaper safety scanner that fits in front of the enclosure. The cheaper Hokuyo UAM-05LP-T301 (refurbished USD 1,347.53) has a 143 x 110 x 110 mm body that does not fit as laid out.
- Assumed until the scanner is bought: its scan plane about 40 mm above its base, 70 ms response, envelope about 107 x 80 x 118 mm, four mounting holes (register item 6).

### Documents changed (new versions)

PLP-CAL-001 v0.7, PLP-REQ-001 v0.9, PLP-PRC-001 v0.9, PLP-PRB-001 v0.6, PLP-DEC-001 v0.5, PLP-DDR-003 v0.5, PLP-BLD-001 v0.5, README, `bom/bom.csv`, `bom/bom-notes.md`, `docs/04-calcs/sizing.py`, `cad/src/model.py` (new clearance checks), `cad/src/product_model.py`.

### Pictures regenerated

General arrangement PLP-DWG-001 Rev P5; concept media (hero, blueprint, cutaway, exploded, flow, viewer; concept sheet Rev P3); all build plan pictures (overview, 11 making sketches PLP-DWG-101 to 111, 10 joints, 15 steps, wiring diagram). Text check on all drawings clean. The earlier note that the pictures were unchanged no longer applies.

### Render scenes exported

Appearance model `cad/src/product_model.py` updated (drive module, release, hoop, scanner and steering stops are now the model's own shapes). `python3 .kit/export_views.py /home/claude/renders/palletpilot` wrote hero, exploded and detail (.npz and .json each) and `palletpilot__jobs.json`. Photoreal images, `card.png` and `social-preview.png` are for Amish's Mac.

### Cross-repo actions

None found for this repo.

### Safety concerns

The personnel stop for follow mode is on paper only. Brakes-only worst case (1.15 m) exceeds the 0.80 m field; TRL 4 must size the field from the scanner's own stopping-distance rules before any trial with people present.

### Recommended next step

Amish decides whether a USD 3,455 scanner line is acceptable against the value-engineering target or whether to pursue a cheaper PL d scanner that fits; TRL 4 remains on hold.

## 2026-10-02: photoreal renders redone on the constructable design

Rendered with Blender Cycles on Amish's Mac from the updated appearance model; captioned with `.kit/photo_caption.py`; `media/card.png` and `media/social-preview.png` regenerated with `.kit/cards.py`. Views: hero, exploded, detail. image_qc passes. Appearance deviations are those logged above as proposed, awaiting Amish.

## 2026-10-03: decisions recorded

Amish decided on 2026-10-03: "PalletPilot - i accept it" (the PL d safety scanner at USD 3,455; kit about USD 5,065 against the USD 1,610 value-engineering target) and "Cost over target - i accept all the cost variations and overruns".

- `docs/06-design-decisions.md` (PLP-DEC-001): row added to decisions made; value engineering section says the overrun was accepted by Amish on 2026-10-03.
- The 2026-10-02 next step (whether the USD 3,455 scanner line is acceptable) is answered; a cheaper PL d scanner stays a saving worth trying. TRL 4 remains on hold.

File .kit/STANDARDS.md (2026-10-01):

---
doc_id: OHP-STD-001
title: Documentation and drawing standard
project: Open Hardware Portfolio
doc_type: Standard
version: "1.7"
status: Released
date: 2026-09-30
author: Amish Chadha
license: CC-BY-SA-4.0
revisions:
  - version: "1.0"
    date: 2026-09-24
    author: Amish Chadha
    change: First release of the standard
  - version: "1.1"
    date: 2026-09-24
    author: Amish Chadha
    change: Adopt Technology Readiness Levels (section 9) for project maturity
  - version: "1.2"
    date: 2026-09-24
    author: Amish Chadha
    change: Portfolio phase cap (section 10), concept media standard (section 11), CLAUDE.md guardrails
  - version: "1.3"
    date: 2026-09-24
    author: Amish Chadha
    change: Scale figure, interactive 3D viewer and flow diagrams added to concept media; session slash commands
  - version: "1.4"
    date: 2026-09-26
    author: Amish Chadha
    change: Every sheet and render names the project and its GitHub repository; overall dimensions, ISO centre lines and 300 dpi PNG on sheets; titles name the device and view labels state the viewing direction; optional photoreal renders with Blender
  - version: "1.5"
    date: 2026-09-27
    author: Amish Chadha
    change: Product renders (section 12), storefront images and image quality check (section 13), public release and release gate (section 14), authorship, citation and commit signing (section 15)
  - version: "1.6"
    date: 2026-09-29
    author: Amish Chadha
    change: Licensing metadata with REUSE (section 16), Zenodo DOI and Software Heritage archiving (section 17), release gate checks REUSE and a single CITATION.cff license, archive.py
  - version: "1.7"
    date: 2026-09-30
    author: Amish Chadha
    change: Concept and constructable design states; design decisions register (DEC) kept apart from the build plan; prototype build plan (BLD, section 18) with pictures by component is required TRL 3 evidence; every repo targets TRL 3 during the populate phase; build_views.py; /to-trl3 and /build-plan commands
---

# Documentation and drawing standard

Every project in the portfolio uses this standard, so that each precis, write-up and sketch looks the same and carries its own version history. The standard ships as a kit in each repo's `.kit/` folder. The kit version is in `.kit/KIT_VERSION`.

## 1. Document types and IDs

Every controlled document has a unique ID in the form `PRJ-TYP-NNN`.

- `PRJ` is the three-letter project code listed in section 7.
- `TYP` is the document type code from the table below.
- `NNN` is a sequence number within that project and type, starting at 001.

| Code | Type | Typical file |
| --- | --- | --- |
| PRC | Design precis | `docs/02-concept.md` |
| PRB | Problem statement | `docs/01-problem.md` |
| REQ | Requirements | `docs/03-requirements.md` |
| CAL | Calculation or sizing note | `docs/04-calcs/*.md` |
| DDR | Design decision record | `docs/decisions/*.md` |
| BOM | Bill of materials | `bom/bom.csv` |
| DWG | Drawing or sketch sheet | `cad/drawings/*.svg` |
| BLD | Prototype build plan (section 18) | `docs/05-build-plan.md` |
| DEC | Design decisions register (section 18) | `docs/06-design-decisions.md` |
| TST | Test plan or test report (front matter adds `environment: lab` or `relevant`) | `docs/05-tests/*.md` |

Example: `TBK-PRC-001` is the ThermaBrick design precis.

## 2. Revision scheme

| Artifact | While in draft | When released | Change after release |
| --- | --- | --- | --- |
| Documents | 0.1, 0.2, 0.3 ... | 1.0 | 1.1 for minor edits, 2.0 for a design change |
| Drawings | Rev P1, P2 ... (preliminary) | Rev A | Rev B, C ... |

- Every change to a controlled document adds a row to its revision history before the commit.
- The `version` field in front matter always equals the newest row in `revisions`. The renderer rejects a document where they differ.
- Status is one of `Draft`, `In review`, `Released` or `Superseded`. Draft and In review documents print with a status band on every page.
- Every release is tagged in Git as `<doc_id>/v<version>`, for example `TBK-PRC-001/v1.0`. Drawings are tagged `TBK-DWG-001/revA`.
- Git history is the full audit trail. The in-document revision table is the human-readable summary.

## 3. Document front matter

Every Markdown document under version control starts with this block:

```yaml
---
doc_id: TBK-PRC-001
title: ThermaBrick design precis
project: ThermaBrick
doc_type: Precis
version: "0.1"
status: Draft
date: 2026-09-24
author: Amish Chadha
license: CERN-OHL-S-2.0
revisions:
  - version: "0.1"
    date: 2026-09-24
    author: Amish Chadha
    change: Initial draft
---
```

Quote version numbers so YAML keeps `1.0` as text instead of turning it into a number. List revisions newest last.

## 4. Writing style

- Chicago Manual of Style.
- No em dashes. Restructure the sentence instead.
- Lead each section with its conclusion, then support it.
- SI units throughout, in the form `12 kW`, `450 °C`, `3.2 m`. Imperial values may follow in parentheses.
- Number every figure and table ("Figure 2", "Table 1") and give each a caption.
- State every assumption in the calculation that depends on it.
- Put safety notes in a blockquote starting with **Safety:**.

## 5. Visual identity

| Element | Specification |
| --- | --- |
| Typeface | IBM Plex Sans for text, IBM Plex Mono for code and values (SIL Open Font License, bundled in `.kit/fonts`) |
| Ink | `#111827` |
| Secondary text | `#4B5563` |
| Rules and grid | `#D1D5DB` |
| Accent (one only) | `#0F766E` teal |
| Document page | US Letter, 20 mm margins |
| Drawing sheet | ANSI B landscape (431.8 x 279.4 mm) |
| Footer | Document ID, version, status, license and designmolecule.com on every page |

## 6. Drawing and sketch conventions

- Units are millimeters unless the title block says otherwise.
- Third-angle projection, marked with the symbol in the title block.
- Line weights: visible outlines 0.5 mm, hidden lines 0.25 mm dashed, center lines 0.18 mm chain.
- The title block contains the project, title, drawing number, revision, scale, units, projection, sheet, author, date, material or notes, and license.
- Every sheet and every render names the project and its GitHub repository (from `repo:` in `project.yaml`), at the top of the sheet and in the title block, so a printed or forwarded sheet is never anonymous.
- The drawing title names the device, not only the drawing type (for example "Handheld near-infrared resin scanner: general arrangement").
- Every view label states its scale and viewing direction (for example "Scale 1:1; side elevation looking along +Y"), and every isometric or render states where it is seen from.
- Orthographic views generated with `add_ortho` carry overall dimensions (length and depth on the top view, height on the front view) and ISO 128 centre lines on cylinders; hidden lines are dashed. Tolerances are not shown before TRL 4.
- Sheets are exported as SVG, PDF and a 300 dpi PNG.
- The revision table in the top right of the sheet lists every revision.
- Concept sketches use the same sheet and title block and carry the label "CONCEPT, NOT FOR FABRICATION".
- Geometry comes from `cad/src/*.py` (build123d). Sheets are generated by `.kit/drawing.py` and never edited by hand.

## 7. Project codes

| Code | Project | Code | Project | Code | Project |
| --- | --- | --- | --- | --- | --- |
| TBK | ThermaBrick | PCF | PicoFlow | HLT | HelioLite |
| CCB | CharCube | DRN | DustRunner | TRT | TremorTrace |
| STC | StepCue | FXH | FlexHand | CPD | ColdPod |
| SCL | SunClave | STR | SteamRoot | GGD | GrainGuard |
| SDL | SeedLine | ZBX | ZeerBox | RMS | RootMesh |
| DWD | DewDrive | SSK | StillStack | PPR | PotPress |
| WWT | WaterWatch | LMF | LumaFlow | FCL | FieldCell |
| CNP | ConePro | CVC | CulvertCrawl | EGD | EmberGuard |
| SNF | SnapFrame | CGM | CargoMule | SCM | StepClimber |
| SWC | SwapCell | PLP | PalletPilot | FTK | FlatTrike |
| WWK | WaterWalker | GRR | GrowRider | SSP | SunSpoke |
| SGN | StepGen | PBX | PowerBox | WML | WasteWise-ml |
| WSC | WasteWise Scan | RFE | ReflowEconomy | | |
| OHP | Portfolio-wide | | | | |

## 8. Build and publish

- `python .kit/render.py` checks every controlled document and renders it to `docs/pdf/<doc_id>_v<version>.pdf`.
- `python .kit/drawing.py` (called from each project's `cad/src/sheets.py`) builds drawing sheets as SVG and PDF in `cad/drawings/`.
- The GitHub Action in `.github/workflows/docs.yml` runs the checks on every push and attaches PDFs to a GitHub Release whenever a release tag is pushed.
- Public releases follow section 14: `python .kit/release_gate.py` must pass, and the release tag is `v0.<TRL>.0` (for example `v0.3.0` at TRL 3).
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

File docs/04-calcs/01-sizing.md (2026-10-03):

---
doc_id: PLP-CAL-001
title: PalletPilot sizing calculations
project: PalletPilot
doc_type: Calculation
version: "0.7"
status: Draft
date: '2026-10-02'
author: Amish Chadha
license: CERN-OHL-S-2.0
revisions:
- version: "0.1"
  date: '2026-09-25'
  author: Amish Chadha
  change: First issue for TRL 3 (mass, axle loads, traction, torque, steering, layered stopping, UWB error budget, energy, geometry, cost, requirement status)
- version: "0.2"
  date: '2026-09-25'
  author: Amish Chadha
  change: Recommendations accepted by Amish (DDR-002)
- version: "0.3"
  date: '2026-09-26'
  author: Amish Chadha
  change: Budget approved by Amish ($1,550 to $1,610, PLP-DDR-002); script rerun; R17 not met to met
- version: "0.4"
  date: '2026-10-01'
  author: Amish Chadha
  change: Rerun on the constructable model (PLP-DDR-003); mass from modelled volumes, release mechanism [G4] and steering range [G5]; budget treated as a value-engineering target
- version: "0.5"
  date: '2026-10-01'
  author: Amish Chadha
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

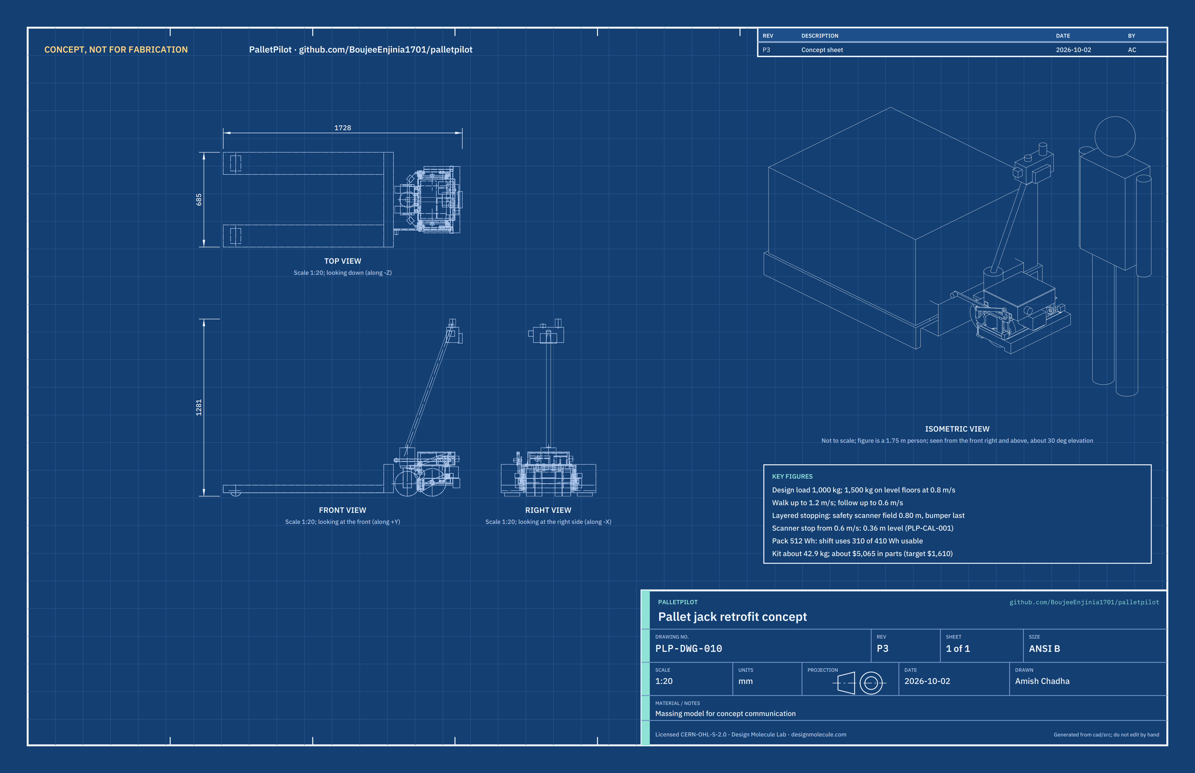
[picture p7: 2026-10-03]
media/concept-blueprint.png

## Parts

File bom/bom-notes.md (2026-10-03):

# BOM notes

- Rows 1 to 13, 18 and 19 match the callouts in `media/exploded.png`, the components table in `docs/02-concept.md` and the parts in `cad/src/model.py`. Rows 14 to 17 are not modelled.
- Every line is priced in USD for one prototype (TRL 3, 2026-09-25). Most prices are estimates for the part class; the lines checked against a live listing are noted below. No supplier has been selected or ordered from.
- Kit total: **$5,065** over 19 lines. Value-engineering target: USD 1,610 (`budget_usd` in `project.yaml`, a hypothetical control target, not a limit; Amish, 2026-10-01). Value-engineering target: USD 1,610. Estimated cost of the constructable design: USD 5,065 (USD 3,455 over the target). The total is checked by `docs/04-calcs/sizing.py` [K1].
- Design for construction (PLP-DDR-003, 2026-10-01): line 1 repriced from $90 to $130 (top plate with notch and hangers, lower jaw, drive arms, pivot pin), line 3 from $45 to $50 (enclosure feet), line 13 from $20 to $45 (cam shaft, cams, crank, link, lever, springs, saddles and straps), line 10 respecified (tube hoop with 0.9 m of safety edge), line 18 respecified (bracket on the hoop), and line 19 added (two rubber steering stops, $10).
- Line 1 (2026-10-02): the 5 mm top plate and two hollow tube pivots (one per drive arm, each with an M12 bolt through its bore) replace the 6 mm plate and the single solid pin; line 13: the lever is a 20 x 10 x 2 mm steel tube. These approved savings cut about 2.0 kg and change no price. Line 10: the safety edge is now 68 mm high (60 to 128 mm above the floor) so the scanner shelf clears it. Line 5: the driver specification adds safe torque off and a monitored controlled-stop input for the personnel stop (no price change assumed). Line 7: the lidar UART is dropped; the scanner's safety outputs go to the safety relay.
- Line 6, contactors: raised from $45 to $75 for a second 24 V main contactor in series, one per safety relay channel (PLP-DDR-002, O6).
- Line 2, hub motors: PLP-CAL-001 needs 25.5 N·m per motor at worst, so the spec is 30 N·m peak. Listed class prices: $165 for a 20/40 N·m, 36 to 48 V motor with no brake listed ([UU Motor SVB8S](https://www.uumotor.com/high-torque-500w-robot-8-inch-servo-hub-motor.html)) and $249 for a 40/80 N·m, 24/48 V motor ([ZLTECH 8 in](https://zltech-hubmotor.en.made-in-china.com/product/NOgmzpqvCLhr/China-Zltech-8inch-24V-48V-200rpm-300kg-Load-Gearless-Electric-DC-Agv-Direct-Drive-Wheel-Hub-Servo-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)). $200 each assumes a 24 V winding with a brake. The 16 N·m peak, $145 class ([UU Motor SVH8S](https://retail.uumotor.com/product/250w-8-inch-encoder-motor-svh8s/)) is too weak.
- Line 18, safety laser scanner (changed 2026-10-02): Amish decided that follow mode is a driverless truck function under ISO 3691-4, so the USD 69 Slamtec RPLIDAR C1 class lidar (not safety-rated) is replaced by a safety laser scanner for personnel detection. Basis: SICK nanoScan3 Core I/O NANS3-AAAZ30AN1 at USD 3,444.30 from [Lesman](https://www.lesman.com/nans3-aaaz30an1) (Type 3, PL d, SIL 2, 3 m protective field, 70 ms response, one OSSD pair, 106.6 x 80 x 117.5 mm including plug, 0.67 kg; [SICK data sheet](https://www.sick.com/media/pdf/9/79/979/dataSheet_NANS3-AAAZ30AN1_1100333_en.pdf)), plus about USD 11 for the 3 mm steel shelf. The cheaper Hokuyo UAM-05LP-T301 (listed new at USD 2,750.00 by [Next Day Automation](https://www.nextdayautomation.com/products/new-hokuyo-uam-05lp-t301-safety-laser-scanner-5m-range-270-protection-24vdc), a surplus dealer, and refurbished at USD 1,347.53 by [Radwell](https://www.radwell.com/Buy/HOKUYO%20AUTOMATIC%20CO/HOKUYO%20AUTOMATIC%20CO/UAM-05LP-T301)) has a 143 x 110 x 110 mm body and a scan plane 100 mm above its base, so it does not fit between the bumper and the enclosure. The scan plane height above the nanoScan3's base (about 40 mm) and its mounting holes are assumed until the part is bought.
- The donor manual pallet jack is not included. A new 27 x 48 in, 2,500 kg (5,500 lb) manual jack costs about $396 ([Global Industrial](https://www.globalindustrial.com/p/global-industrial-153-standard-duty-pallet-jack-truck-5500-lb-capacity-27-x-48-forks)).
- This BOM is a costed design list, not a purchasing list. Buying parts is TRL 4 work and is on hold by Amish's instruction.

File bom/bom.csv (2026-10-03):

item | qty | spec | supplier | unit_cost_usd | make_buy | notes
1 Drive module: subframe, lower jaw, drive arms and pivot | 1 | 5 mm steel top plate about 295 x 400 mm with a notch round the jack's pump, welded hangers and brackets; 10 mm lower jaw with a packing bar that grips the donor yoke plate's rear edge with four M12 bolts (no drilling of the jack); two 10 mm steel drive arms each on its own 20 mm hollow tube pivot (4 mm wall, M12 bolt through the bore) behind the wheels, each with a spring tab | Local fabricator (laser-cut plate and bending) | 130.00 | make | Estimate for one prototype, laser-cut plate with welding; clamp fit depends on the donor yoke (R1 survey); about 10.6 kg; made constructable in PLP-DDR-003 (was $90); 5 mm top plate and hollow pivots carried into the model 2026-10-02 (PLP-DDR-003 A2); price unchanged
2 Hub motors with spring-applied brakes | 2 | 24 V brushless gearless hub servo motor, 200 mm (8 in) polyurethane or rubber tread, 12 N m or more continuous and 30 N m or more peak, fail-safe brake 20 N m or more dynamic, encoder, IP54 or better, about 7 kg | AGV hub motor maker (ZLTECH or UU Motor class) | 200.00 | buy | Per motor; class prices USD 165 (UU Motor SVB8S; 20/40 N m; 36 to 48 V; no brake listed) to USD 249 (ZLTECH 8 in 24/48 V; 40/80 N m); brake option and 24 V winding to confirm; TRL 2 figure of $170 was for a 16 N m class motor that is too weak
3 Battery and electronics enclosure | 1 | Folded 2 mm aluminium box 270 x 300 x 96 mm with lid, cable glands, IP54; four riveted angle feet bolted to the top plate; height set so the donor handle clears it when lowered to horizontal | Local sheet metal shop | 50.00 | make | Estimate; about 1.8 kg; feet added in PLP-DDR-003 (was $45); 1 mm deeper (96 mm) to sit on the 5 mm top plate
4 LiFePO4 pack with BMS | 1 | 8S 25.6 V 20 Ah (512 Wh) LiFePO4, 8S6P 26650 cells in three layers about 270 x 115 x 85 mm, BMS 50 A continuous, charge temperature cut-off below 0 degC | LiFePO4 pack assembler | 180.00 | buy | Estimate from retail 24 V 20 Ah packs; about 4.9 kg; 410 Wh usable at 80 % depth of discharge
5 Dual-channel motor driver | 1 | 24 V dual-channel brushless servo driver for the hub motors, 2 x 15 A continuous and 30 A peak, CAN, brake outputs, safe torque off and a monitored controlled-stop (stop category 1) input | AGV hub motor maker (sold with the motors) | 150.00 | buy | Estimate; match to the chosen motor's encoder and brake; safe torque off added to the specification for the ISO 3691-4 stopping function (no price change assumed; to confirm at the motor quote)
6 Contactors fuse and disconnect | 1 | 80 A main fuse at the pack terminal, two 24 V main contactors in series (each opened by one safety relay channel) with pre-charge resistor, lockable battery disconnect | Electronics distributor | 75.00 | buy | Estimate; second contactor (about USD 30) added for a dual-channel stop chain toward PL d (PLP-DDR-002; O6); about 1.1 kg
7 Controller and safety relay | 1 | ESP32-S3 class controller with CAN transceiver, UWB SPI links; dual-channel safety relay for the stop chain, taking the scanner's OSSD pair | Electronics distributor | 85.00 | buy | Estimate (controller about $25; safety relay about $60); firmware is not TRL 3 work
8 Tiller control head | 1 | Clamp-on head replacing the grip: thumbwheel throttle, belly-reverse paddle, mode key switch (walk or follow), horn button, beacon mount | Industrial controls supplier | 70.00 | buy | Estimate; generic walkie tiller-head parts
9 Emergency stops | 2 | 22 mm red mushroom pushbutton, twist release, two normally closed contacts, yellow backing plate (ISO 13850 style) | Industrial controls supplier | 15.00 | buy | Per unit; one on the tiller head and one on the enclosure rear face
10 Contact bumper | 1 | Pressure-sensitive safety edge about 0.9 m in three lengths (front 480 mm and both sides) with evaluation unit, 40 mm compression travel at the front, on a 40 x 20 x 2 mm steel tube U hoop bolted to the subframe brackets with M8 rivet nuts | Safety edge supplier | 110.00 | buy | Estimate; last stopping layer; about 2.3 kg with hoop; safety edge 68 mm high (60 to 128 mm above the floor) so the scanner shelf clears it
11 UWB anchors | 3 | Qorvo DWM3000 class UWB module on a carrier board: two on the bumper corners (450 mm baseline), one on the tiller head | Electronics distributor | 25.00 | buy | Per unit
12 Status beacon and buzzer | 1 | 24 V LED beacon on the tiller head, amber in walk mode and blue in follow mode, with travel buzzer | Electronics distributor | 25.00 | buy | Estimate; moved from the lid to the tiller head so the lowered handle clears the enclosure
13 Manual release mechanism | 1 | 16 mm steel cam shaft with two 22 mm eccentric cams and a crank, release link, 400 mm over-center lever of 20 x 10 x 2 mm steel tube with grip, two preload springs (about 100 N/mm, 34 mm outside diameter), two spring saddles and four slotted lift straps; raises the spring saddles and lifts the drive wheels about 10 mm clear of the floor | Local fabricator plus spring supplier | 45.00 | make | Estimate; peak lever effort about 58 N (PLP-CAL-001 [G4]); made constructable in PLP-DDR-003 (was $20 for the lever and cam alone); lever now a steel tube (2026-10-02)
14 Battery charger | 1 | Certified 29.2 V 5 A LiFePO4 charger, 100 to 240 V AC input | LiFePO4 charger maker | 45.00 | buy | Estimate; not modelled; stays at the charging point
15 Operator UWB tag | 1 | Belt tag with UWB module, rechargeable cell, stop button and vibration alert | Electronics distributor | 45.00 | buy | Estimate; not modelled
16 Handle angle sensor and gas spring | 1 | Hall angle sensor on the handle pivot; gas spring that holds the handle upright in follow mode | Electronics distributor | 25.00 | buy | Estimate; not modelled
17 Wiring and hardware | 1 | 10 AWG power cable, spiral wrap to the tiller head, connectors, fasteners, labels | Electronics distributor | 60.00 | buy | Estimate; not modelled
18 Safety laser scanner and bracket | 1 | Safety laser scanner for personnel detection (SICK nanoScan3 Core I/O class: 3 m protective field, 275 deg, 70 ms response, Type 3, PL d, SIL 2, 24 V, one OSSD pair, IP65, about 107 x 80 x 118 mm and 0.67 kg), on a 3 mm steel shelf bolted to the top of the bumper hoop's front bar, scan plane about 173 mm above the floor | Industrial automation distributor (SICK) plus local fabricator | 3455.00 | buy | USD 3,444.30 scanner (NANS3-AAAZ30AN1, listed by Lesman) plus about USD 11 shelf; safety-rated, replaces the USD 69 RPLIDAR C1 class lidar (approved 2026-10-02: follow mode under ISO 3691-4); field set by the stopping calculation (PLP-CAL-001 S4); mounting holes, scan plane height above its base (about 40 mm) and response time to confirm at purchase
19 Steering stops | 2 | Two 40 x 40 x 20 mm hard rubber blocks (about 80 Shore A) bolted under the top plate's front corners with two M8 bolts each; they meet the jack's frame head at 40 deg of steer, before any other kit part | Industrial rubber supplier | 5.00 | buy | Added in PLP-DDR-003; stop angle set to the donor surveyed (R1)

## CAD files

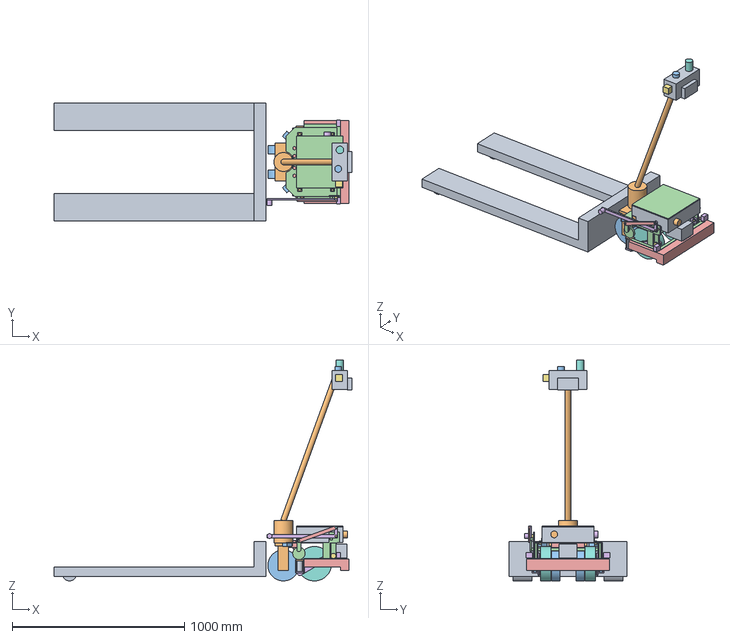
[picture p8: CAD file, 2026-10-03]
cad/step/palletpilot-assembly.step
1727.8 x 685.0 x 1280.7 mm

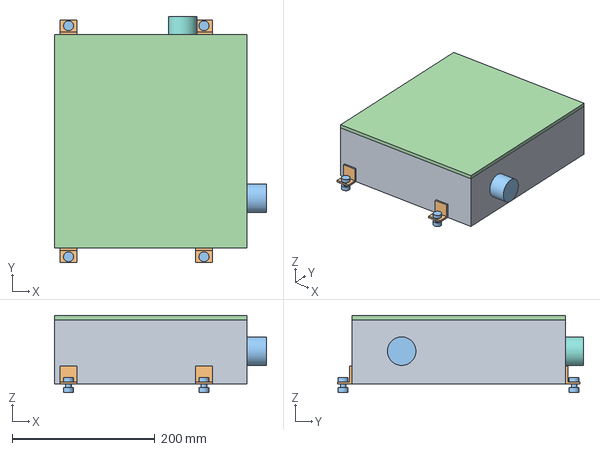
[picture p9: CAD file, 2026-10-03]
cad/step/enclosure.step
298.0 x 345.0 x 108.0 mm

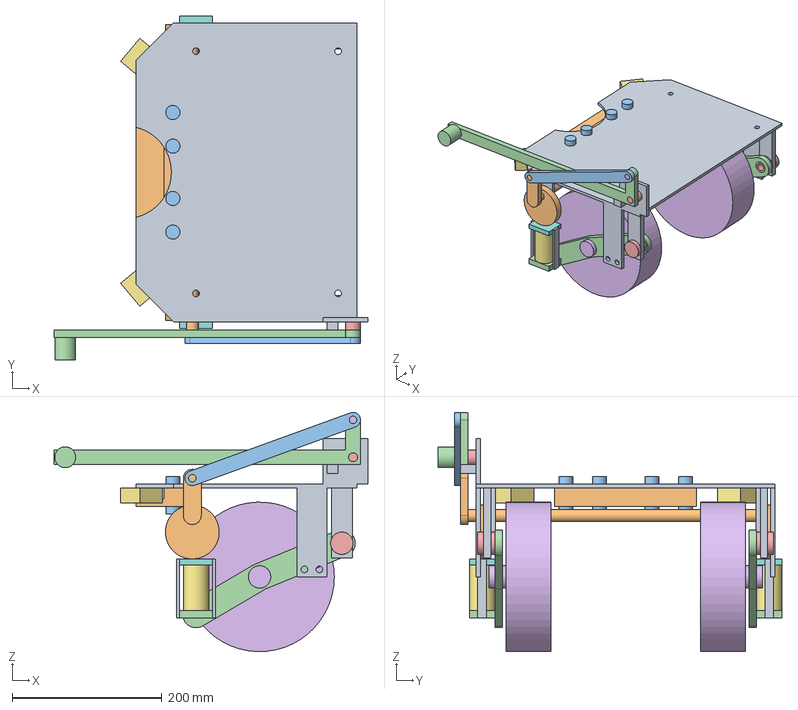
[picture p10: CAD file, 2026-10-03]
cad/step/drive-module.step
420.0 x 460.0 x 320.0 mm

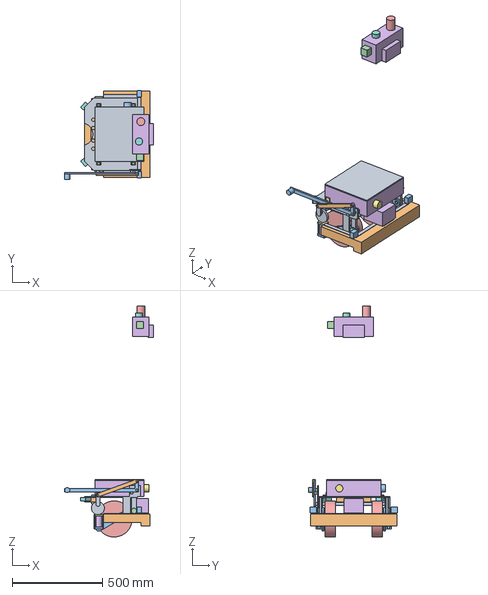
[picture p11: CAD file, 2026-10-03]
cad/step/palletpilot-kit.step
492.8 x 494.0 x 1280.7 mm

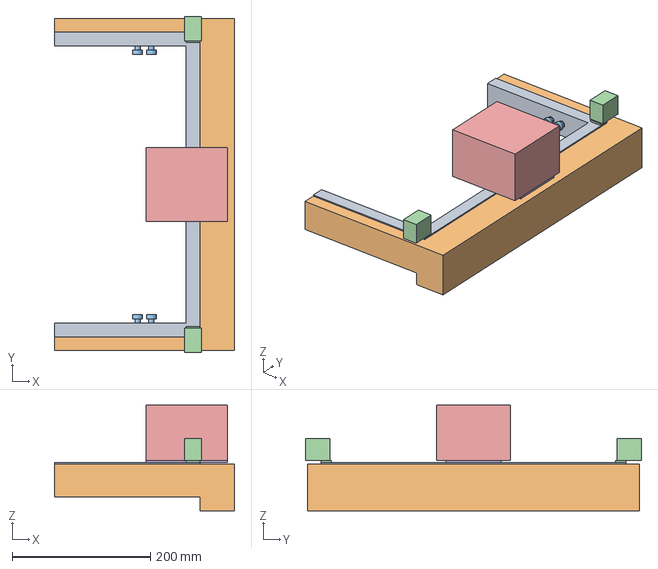
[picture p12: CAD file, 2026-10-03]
cad/step/bumper-and-sensors.step
260.0 x 486.0 x 153.0 mm

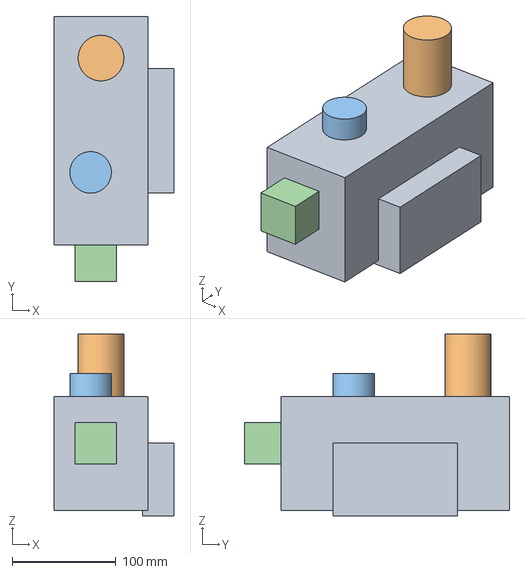
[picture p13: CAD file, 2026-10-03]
cad/step/tiller-head.step
115.0 x 255.0 x 175.0 mm

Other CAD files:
cad/stl/bumper-and-sensors.stl
cad/stl/drive-module.stl
cad/stl/enclosure.stl
cad/stl/palletpilot-assembly.stl
cad/stl/palletpilot-kit.stl
cad/stl/tiller-head.stl

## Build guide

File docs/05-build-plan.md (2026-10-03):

---
doc_id: PLP-BLD-001
title: PalletPilot prototype build plan
project: PalletPilot
doc_type: Build plan
version: "0.5"
status: Draft
date: '2026-10-02'
author: Amish Chadha
license: CERN-OHL-S-2.0
revisions:
  - version: "0.1"
    date: '2026-10-01'
    author: Amish Chadha
    change: First build plan; design made constructable (PLP-DDR-003)
  - version: "0.2"
    date: '2026-10-01'
    author: Amish Chadha
    change: Steering range stated in section 3.2 (about 40° each way, turning radius roughly 1.5 m about the load wheels); aisle turn added to the first checks
  - version: "0.3"
    date: '2026-10-02'
    author: Amish Chadha
    change: "Release for smooth indoor floors only; safety stop S7 treats follow mode under ISO 3691-4 (decided by Amish on 2026-10-02)"
  - version: "0.4"
    date: '2026-10-02'
    author: Amish Chadha
    change: "Section 2: the Table 1 changes of PLP-DDR-003 accepted by Amish on 2026-10-02"
  - version: "0.5"
    date: '2026-10-02'
    author: Amish Chadha
    change: "Approved follow-ups carried in: 5 mm top plate, tube lever, two hollow pivot tubes, safety laser scanner on a shelf in place of the lidar; pictures and sizes updated"
---

# PalletPilot prototype build plan

**Plan, not yet built.** How to build the first proof-of-concept prototype, component by component. Building and testing to it is TRL 4 work. Decisions still to be made are kept in the design decisions register ([docs/06-design-decisions.md](06-design-decisions.md)), not here.

## 1. What you are building

Figure 1. Every component of the kit, pulled apart and numbered in build order

*Figure 1. The 17 components of the kit, pulled apart and numbered in build order. The donor jack is not shown.*

The prototype is the PalletPilot kit fitted to one ordinary 27 x 48 in manual pallet jack. Everything hangs off the jack's steering yoke, behind its pump: a steel subframe clamped to the yoke plate, two hub motors on sprung drive arms, a release lever that lifts the motors clear for pushing by hand, a low aluminium box holding the battery and electronics, a bumper hoop with a safety edge, a safety laser scanner and two radio anchors on the hoop, and a new control head on the jack's handle. Figure 1 shows the 17 components in the order you make or fit them. Eleven are made in a small fabrication shop: the subframe, lower jaw, drive arms, pivot tubes, cam shaft, spring saddles and straps, lever, link, enclosure, bumper hoop and scanner shelf. The rest are bought: the hub motors, springs, steering stops, battery, motor driver, contactors, controller, safety edge, safety scanner, anchors and tiller head. The work is cutting and drilling steel plate, MIG welding, bending strip, folding aluminium sheet, riveting, and wiring bought modules at 25.6 V. The parts cost about $5,065 from the bill of materials, most of it the safety scanner. Nothing is drilled, cut or welded on the jack itself.

> **Safety:** The finished kit is moving machinery that can push a 1,000 kg load, and it carries a 512 Wh lithium iron phosphate battery that can deliver very high currents. Keep the battery fuse out and the disconnect off until section 6 says otherwise, keep the drive wheels lifted (lever up) and the jack chocked for every powered check, and never ride on the jack. Welding, grinding and cutting steel need eye, hand and fire precautions. The kit is a research prototype for a closed area and is not a certified industrial truck.

## 2. What changed to make it buildable

The concept showed what the kit does; several of its parts could not be made or fixed as drawn. Each change below keeps what the kit does, and all of them are recorded in decision record PLP-DDR-003; Amish accepted the changes in its Table 1 on 2026-10-02.

*Table 1. Changes from the concept.*

| Component | The concept had | The buildable design has | Why |
| --- | --- | --- | --- |
| Yoke clamp | A thick slab with a block that did not reach the yoke and a loose tongue under it | A 5 mm top plate on the yoke plate with a notch round the pump, a lower jaw underneath, and four M12 bolts behind the yoke's edge (Figure 6) | Grips the yoke plate without drilling the jack |
| Drive wheel mounts | Side cheeks welded solid to the plate, and springs floating beside it | Two drive arms, each on a hollow pivot tube behind its wheel, each pushed down by a spring at its front end (Figures 7 and 12) | The wheels can follow the floor and carry the 1.5 kN preload |
| Hub motors | Wheels with no shaft into their mounts | Each motor's shaft passes through its arm with a spacer and a nut (Figure 7) | How a single-sided hub motor is mounted |
| Manual release | A lever along the box with no pivot and no link to the springs | A cam shaft with two cams, a crank, a link and a 400 mm steel tube lever; raising the lever lifts the wheels 10 mm (Figures 15 and 16) | One lever lifts both wheels with about 58 N of effort |
| Bumper | One solid block, mounted from the moving cheeks | A tube hoop bolted to brackets on the subframe, with the safety edge riveted on (Figure 21) | The bumper face no longer moves with the wheels |
| Scanner and anchors | A lidar on a bracket in space the arms now need, and anchors with no fixing | A safety laser scanner for personnel detection on a flat steel shelf, and two corner plates, screwed to the top of the hoop (Figure 23) | The follow mode stop must meet ISO 3691-4; the scan plane is 173 above the floor and the anchor spacing is unchanged |
| Enclosure | No fixing | Four riveted angle feet, one M8 bolt each (Figure 18) | The box floor stays whole |
| Steering | Nothing stopped the drive end swinging into the jack's frame | Corners of the top plate cut back and two rubber steering stops that meet the frame at 40° (Figure 3) | Steel parts of the kit never strike the jack |

## 3. Making the components

Make and check each component before the assembly step that needs it. Sizes are in millimetres. "Front" is the end of the kit nearest the jack's forks; "back" is the handle end. "Left" and "right" are as seen standing at the handle end, facing the forks; the release lever is on the left. Workshop tolerance is 0.5 mm unless a step says otherwise; drawings do not carry tolerances before TRL 4. Before cutting anything, measure the donor jack's yoke plate (thickness, rear edge, width) and the distance from its steering axis to the back of its frame; the plan assumes a 15 mm yoke plate whose rear edge is 50 mm behind the steering axis and a frame 100 mm ahead of it.

### 3.1 Subframe (top plate with welded hangers and brackets)

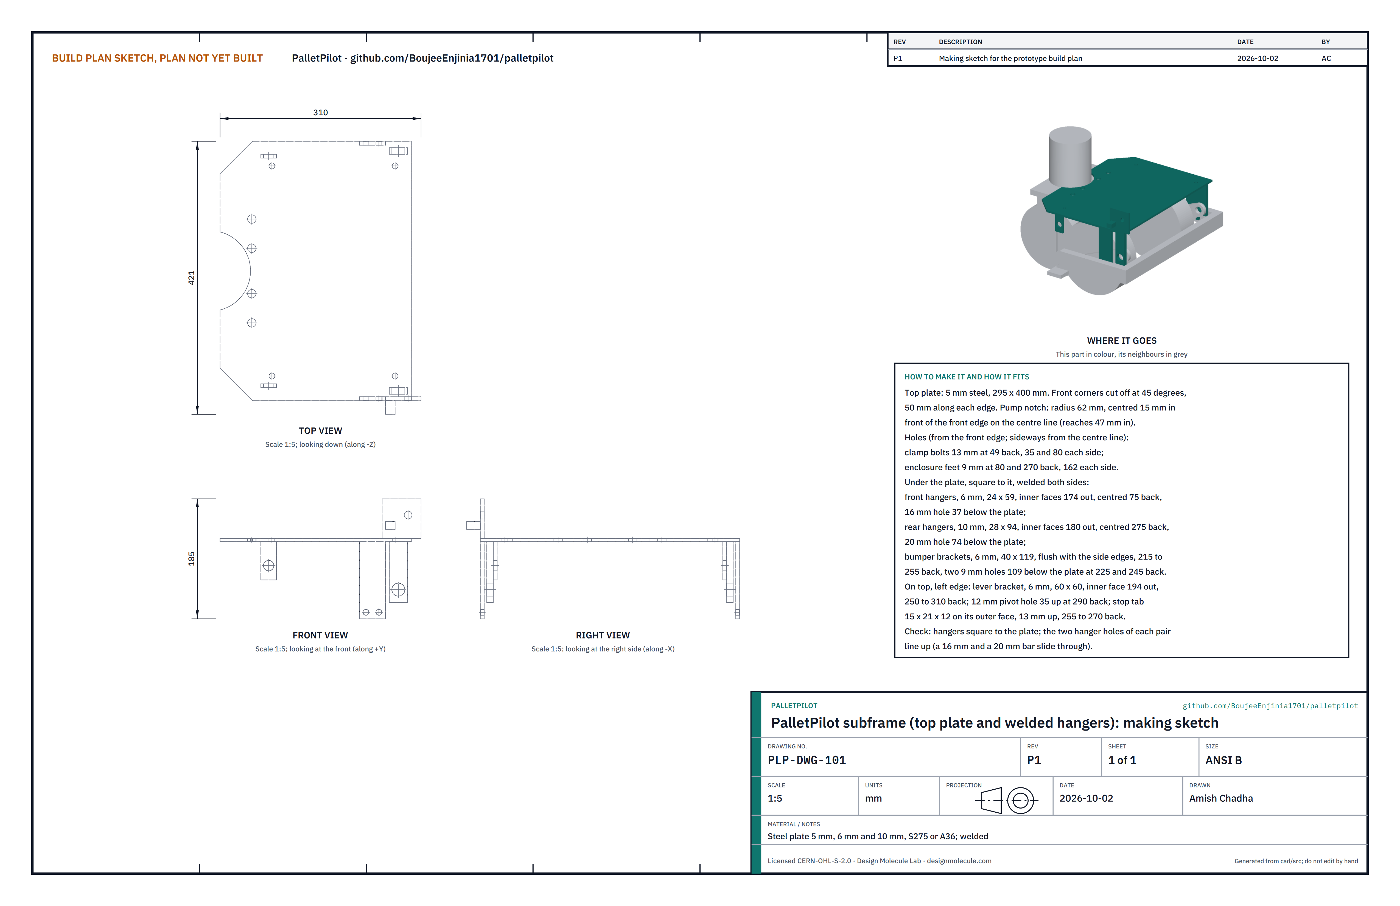
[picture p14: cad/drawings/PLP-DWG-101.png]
Figure 2. Making sketch of the subframe


*Figure 2. Subframe making sketch (PLP-DWG-101).*

**What it is and what it is made from.** The plate everything hangs from. It sits on the jack's yoke plate, carries the enclosure on top and, underneath, the hangers for the cam shaft and the drive arms and the brackets for the bumper. Steel plate, S275 or A36 class: 5 mm for the top plate; 6 mm for the front hangers, bumper brackets and lever bracket; 10 mm for the rear hangers.

**How to make it.**

1. Have the top plate laser or plasma cut: 295 x 400, front corners cut off at 45° for 50 along each edge, and a half-round notch of 62 radius in the front edge, centred on the centre line 15 in front of the edge, so it reaches 47 into the plate.
2. Drill the top plate, measuring back from the front edge and sideways from the centre line: four 13 mm clamp bolt holes 49 back, at 35 and 80 each side; four 9 mm enclosure foot holes at 80 and 270 back, 162 each side.
3. Cut the two front hangers (6 mm, 24 x 59) and drill a 16 mm hole in each, 37 from the top edge, centred. Cut the two rear hangers (10 mm, 28 x 94) and drill a 20 mm hole in each, 74 from the top edge, centred.
4. Cut the two bumper brackets (6 mm, 40 x 119) and drill two 9 mm holes in each, 109 from the top edge, 10 and 30 from the back edge.
5. Cut the lever bracket (6 mm, 60 x 60) and drill a 12 mm pivot hole 35 above its bottom edge, 40 from its front end. Cut the stop tab (15 x 21 x 12).
6. Tack the parts under the top plate, square to it: front hangers with their inner faces 174 from the centre line, centred 75 back; rear hangers with inner faces 180 out, centred 275 back; bumper brackets flush with the side edges, 215 to 255 back. Slide a 16 mm bar through both front hangers and a 20 mm bar through both rear hangers before welding, so the holes stay in line.
7. Tack the lever bracket on top of the plate at the left edge, inner face 194 from the centre line, 250 to 310 back (it overhangs the back edge by 15), and the stop tab on its outer face, 13 above the plate, 255 to 270 back.
8. Weld everything with short alternating runs to limit distortion, then check the plate is flat within 1 mm. Deburr, and paint or powder coat.

**How it fits the parts next to it.** The front of the plate rests on the yoke plate's rear margin with the pump in the notch, 7 clear all round; the lower jaw grips the yoke plate from below (Figure 6). The drive arms hang from the rear hangers (Figure 10), the cam shaft runs in the front hangers (Figure 4), the bumper hoop bolts to the brackets (Figure 21) and the enclosure feet bolt through the top (Figure 18).

**Check before moving on.** The 16 mm and 20 mm bars slide through each pair of hangers by hand; the hangers are square to the plate; the plate is flat within 1 mm.

### 3.2 Steering stops (bought, make 2)

**What it is and what it is made from.** A hard rubber block (about 80 Shore A), 40 x 40 x 20, under each front corner of the top plate. The stops set how far the jack steers with the kit fitted: about 40° each way, against about 90° for a bare jack, for a turning radius of roughly 1.5 m about the load wheels.

**How to make it.**

1. Buy two blocks with a bonded steel backing plate, or cut them from hard rubber sheet.
2. Mark the block's position from Figure 3: its outer face must lie flat on the back of the jack's frame when the handle is turned 40° to that side, and nothing else may touch the frame first.
3. Drill two 9 mm holes through the top plate and the block and fit two M8 bolts with large washers and nyloc nuts.

**How it fits the parts next to it.**

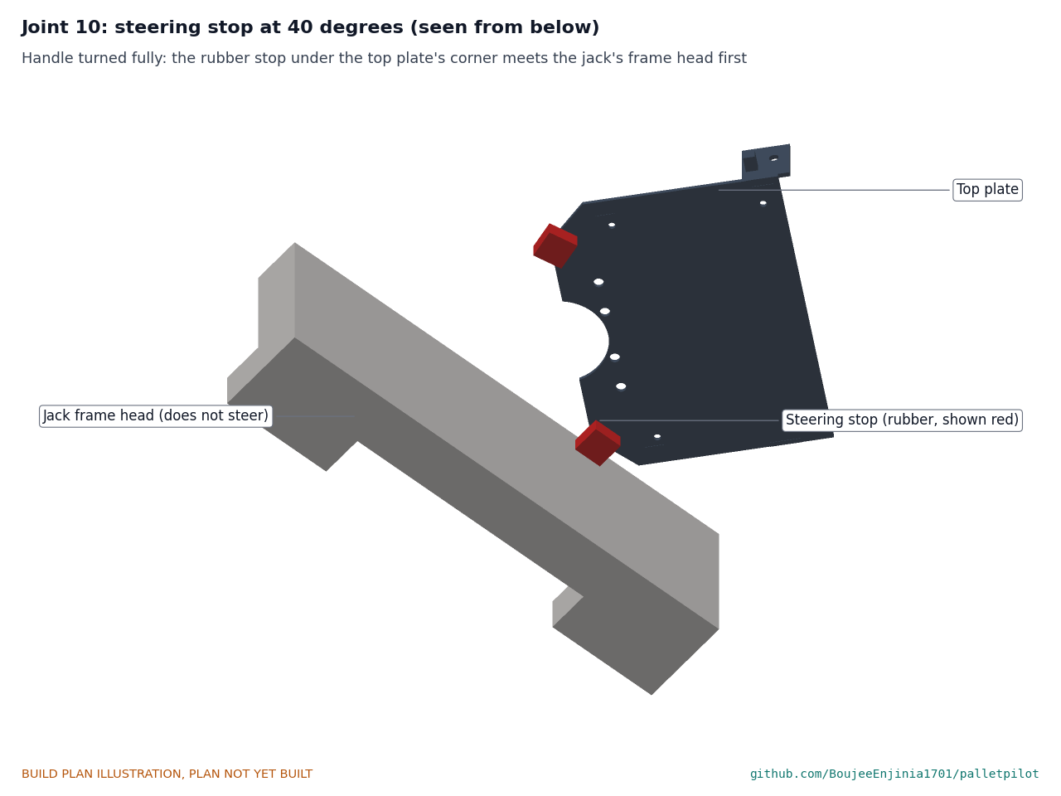
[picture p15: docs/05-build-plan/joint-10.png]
Figure 3. Joint 10: a steering stop meeting the jack's frame at full turn


*Figure 3. At 40° of turn the rubber stop meets the jack's frame head flat; the hub motors, the hoop and the plate are still clear.*

**Check before moving on.** After step 6, turn the handle fully each way: the stop must touch the frame before any steel part of the kit, with about 4° to spare. If your jack's frame sits further from the steering axis than 100 mm, the stops can be moved out to allow more turn.

### 3.3 Cam shaft, cams and crank

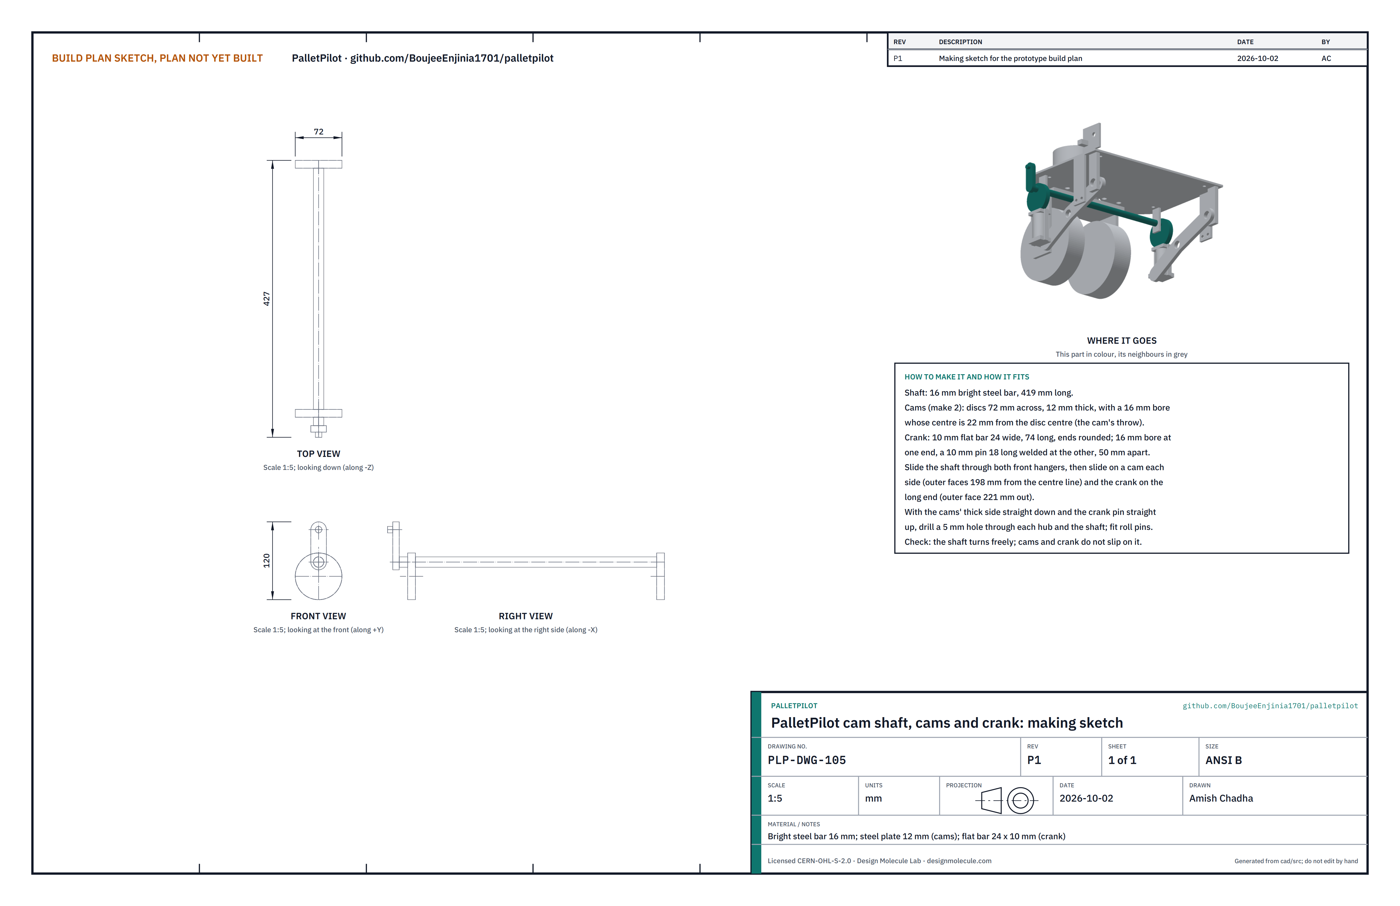
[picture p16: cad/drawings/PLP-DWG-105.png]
Figure 4. Making sketch of the cam shaft


*Figure 4. Cam shaft making sketch (PLP-DWG-105).*

**What it is and what it is made from.** The shaft that the release lever turns. Its two cams press the spring saddles down when the wheels are down and let them rise 22 when the lever is raised. 16 mm bright steel bar; cams from 12 mm steel plate; crank from 24 x 10 flat bar with a 10 mm pin.

**How to make it.**

1. Cut the shaft 419 long and chamfer both ends.
2. Have two cams cut: discs 72 across with a 16 mm bore whose centre is 22 from the disc's centre. Ream the bores to a sliding fit on the shaft.
3. Make the crank: 74 long, ends rounded, a 16 mm bore at one end and a 10 mm pin, 18 long, welded into a hole at the other, 50 between centres.
4. The shaft, cams and crank are assembled in the subframe's front hangers (step 2), because the cams sit outside the hangers.
5. With the shaft in the hangers, slide a cam on each end with its outer face 198 from the centre line, and the crank on the long (left) end with its outer face 221 out. Turn the cams so their thick side points straight down and the crank pin straight up, then drill a 5 mm hole through each hub and the shaft and drive in a roll pin.

**How it fits the parts next to it.** The shaft turns in the front hangers (grease it). Each cam bears on the top of a spring saddle (Figure 12). The crank pin carries the link (Figure 15).

**Check before moving on.** The shaft turns freely by hand; cams and crank do not move on it.

### 3.4 Lower jaw and packing bar

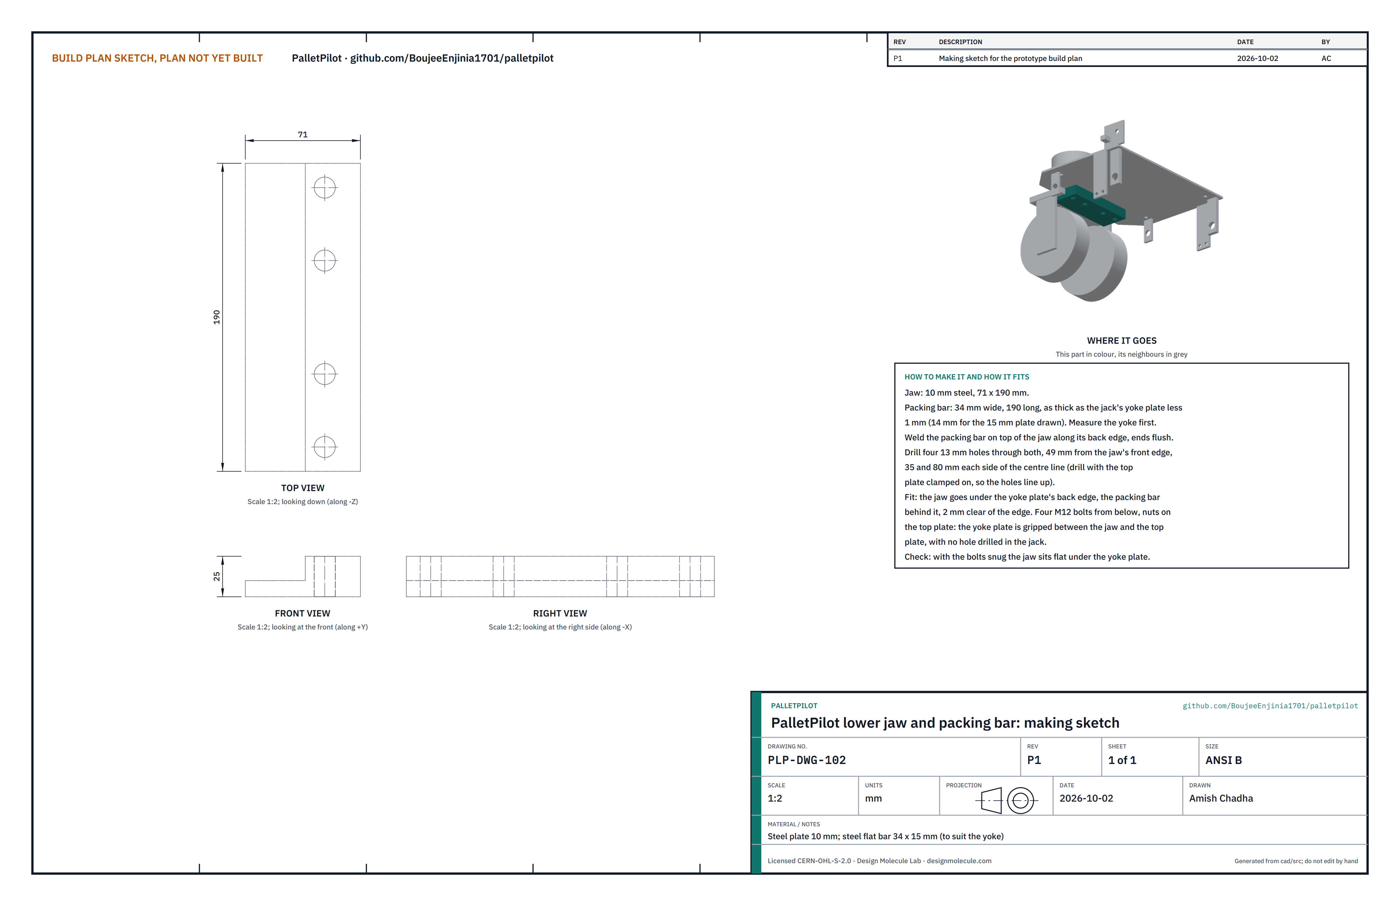
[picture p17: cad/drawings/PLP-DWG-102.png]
Figure 5. Making sketch of the lower jaw


*Figure 5. Lower jaw making sketch (PLP-DWG-102).*

**What it is and what it is made from.** The plate that grips the jack's yoke plate from below. 10 mm steel plate for the jaw; a flat bar 34 wide for the packing bar, as thick as your yoke plate less 1 mm.

**How to make it.**

1. Cut the jaw 71 x 190.
2. Cut the packing bar 190 long and weld it on top of the jaw along its back edge, ends flush.
3. Clamp the jaw under the top plate, packing bar between them, back edges flush, and drill the four 13 mm holes through both from the top plate's holes.

**How it fits the parts next to it.**

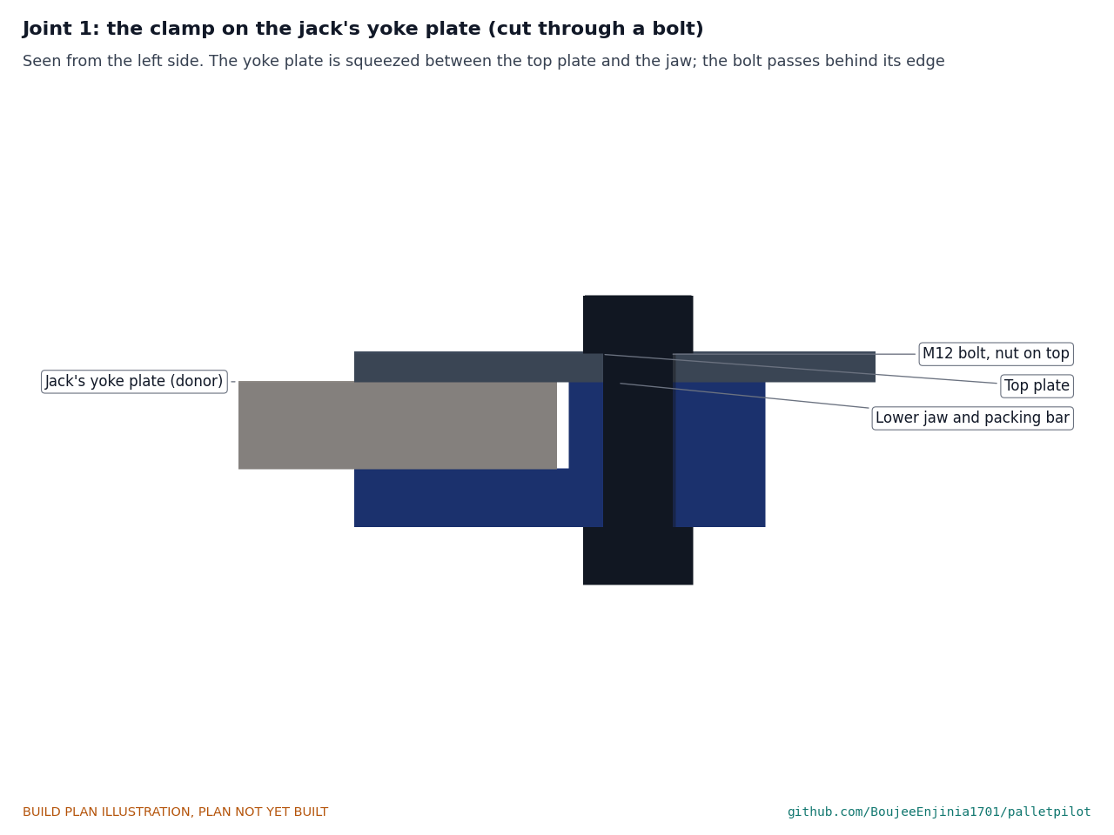
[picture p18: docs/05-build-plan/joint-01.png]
Figure 6. Joint 1: the clamp on the jack's yoke, cut through the right-hand bolts


*Figure 6. The yoke plate is gripped between the top plate and the jaw; the packing bar sits 2 behind the yoke's edge; the bolts pass behind the edge, so the jack is not drilled.*

The jaw's front part lies under the yoke plate's rear margin, 35 deep. Four M12 bolts go up from below, through the jaw, the packing bar and the top plate, with nuts on top. Because the packing bar is 1 mm thinner than the yoke plate, tightening the bolts squeezes the yoke plate. The pump in the notch stops the subframe sliding back; the packing bar against the yoke's edge stops it sliding forward.

**Check before moving on.** With the bolts snug, the jaw sits flat under the yoke plate along its whole width.

### 3.5 Hub motors (bought, make up 2 with their arms)

**What it is.** Two 24 V brushless hub servo motors, 200 mm, 30 N·m peak or more, with spring-applied brakes and a single fixed shaft on one side (bill of materials line 2). Each is fitted to its drive arm on the bench (step 5).

**How it fits the parts next to it.**

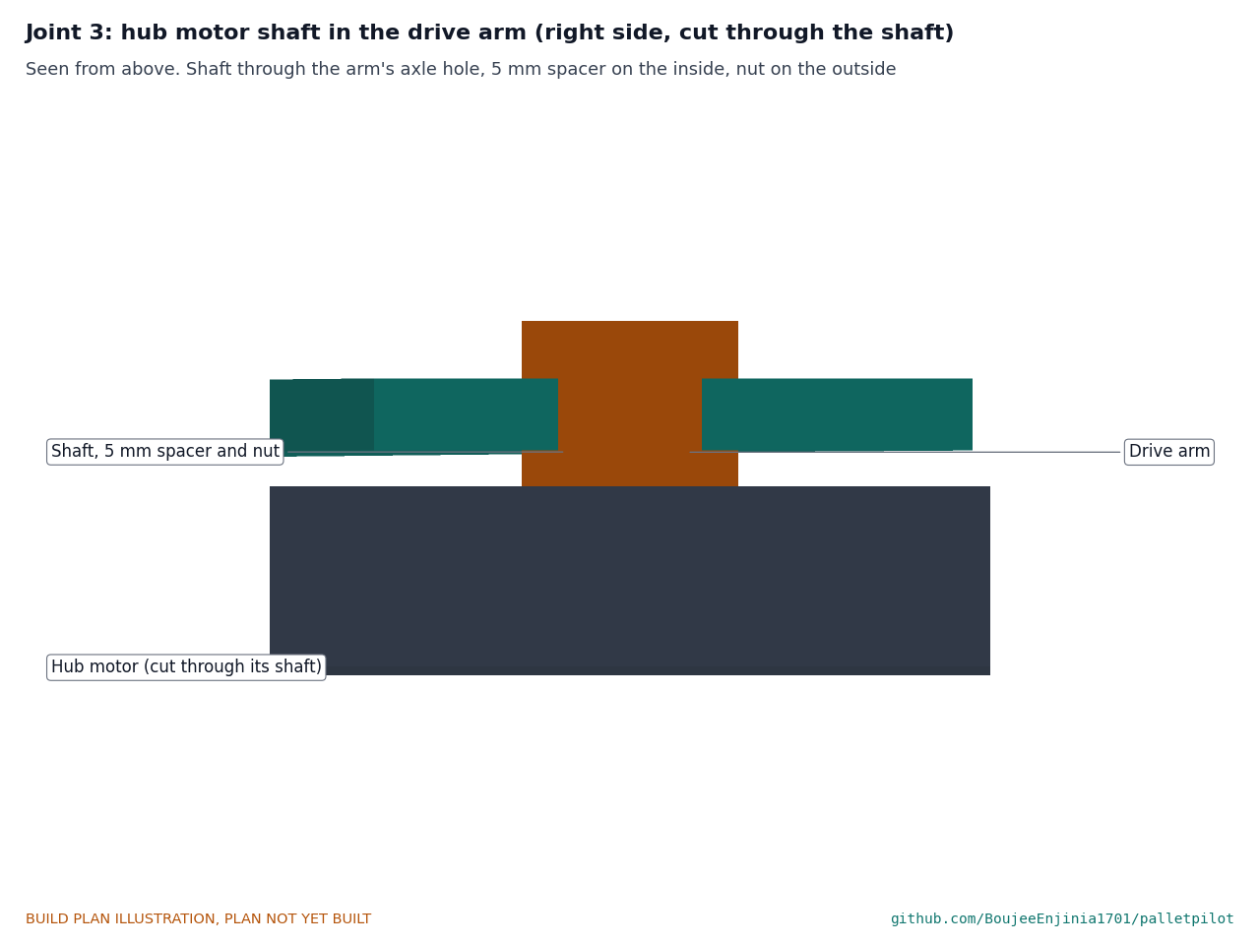
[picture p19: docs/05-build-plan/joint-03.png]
Figure 7. Joint 3: hub motor shaft in the drive arm


*Figure 7. The motor's shaft passes through the arm's axle hole, with a 5 mm spacer between the motor and the arm and a nut outside.*

**Check before moving on.** The shaft's flats (if it has them) seat in the arm without play; the motor's cable leaves on the side away from the floor.

### 3.6 Drive arms (make 2, a left and a right)

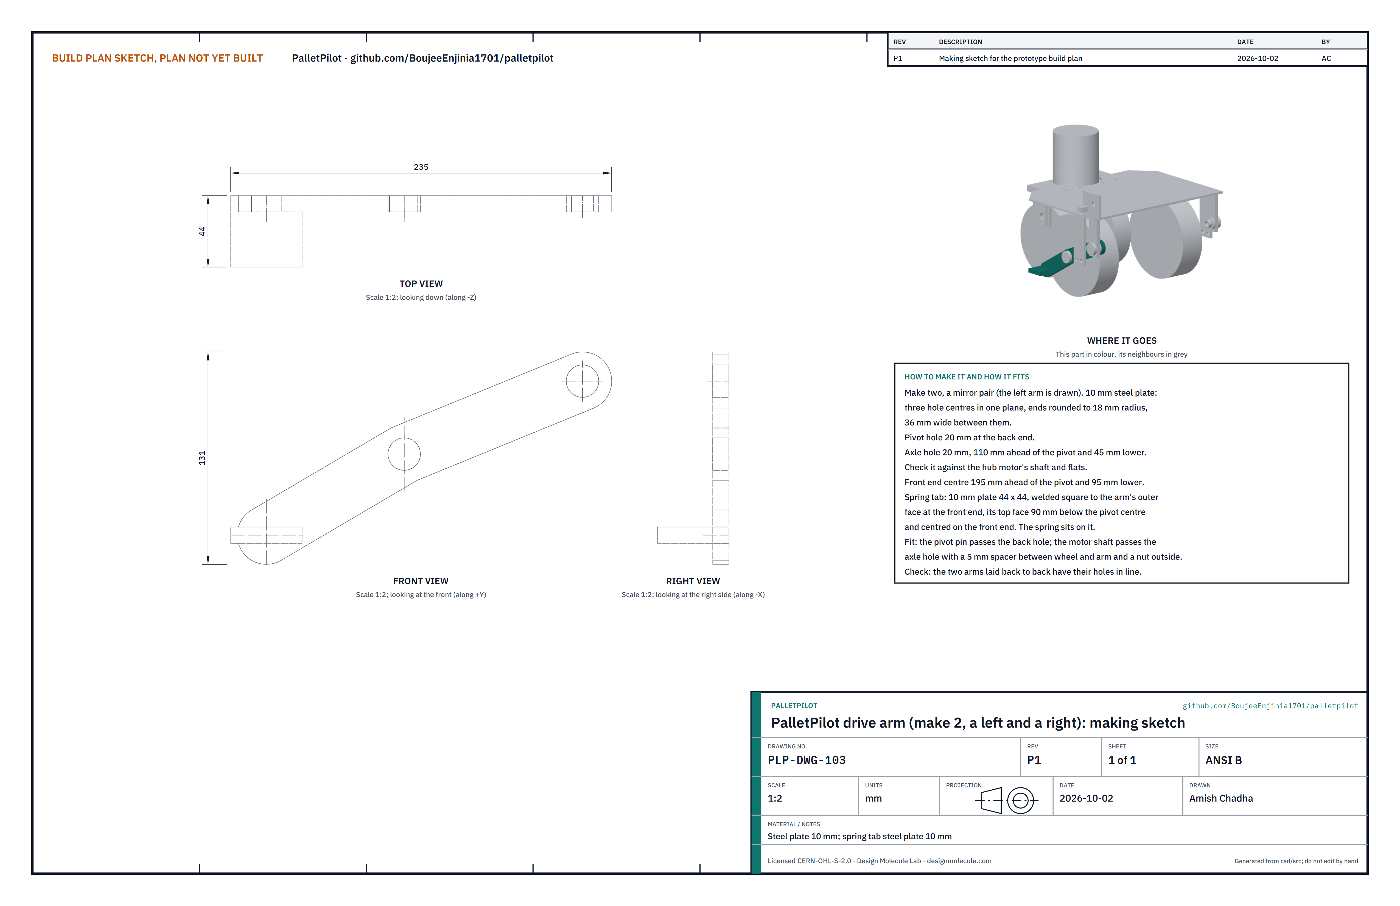
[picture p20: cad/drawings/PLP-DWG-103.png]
Figure 8. Making sketch of the drive arm


*Figure 8. Drive arm making sketch (PLP-DWG-103).*

**What it is and what it is made from.** The arm that carries one hub motor and pivots behind it, so the spring at its front end can push the wheel onto the floor. 10 mm steel plate, with a 10 mm spring tab welded on.

**How to make it.**

1. Have the two arms cut as a mirror pair from the profile: a 20 mm pivot hole at the back end; a 20 mm axle hole 110 ahead of it and 45 lower; the front end's centre 195 ahead of the pivot and 95 lower. Ends rounded to 18 radius, 36 wide between.
2. Check the axle hole against the hub motor's shaft and opt for a flatted hole if the shaft has flats.
3. Cut two spring tabs 44 x 44 from 10 mm plate. Weld one to the outer face of each arm at the front end, square to the arm, its top face 90 below the pivot hole centre, reaching 34 out from the arm.
4. Drill and tap an M6 hole into the middle of each tab's front and back edges, 5 below its top face (for the lift straps).

**How it fits the parts next to it.** Each pivot tube passes through the back hole of its arm (Figure 10), the motor shaft through the axle hole (Figure 7), and the spring stands on the tab (Figure 12).

**Check before moving on.** Laid back to back, the two arms' holes line up.

### 3.7 Pivot tubes, spacers and bolts

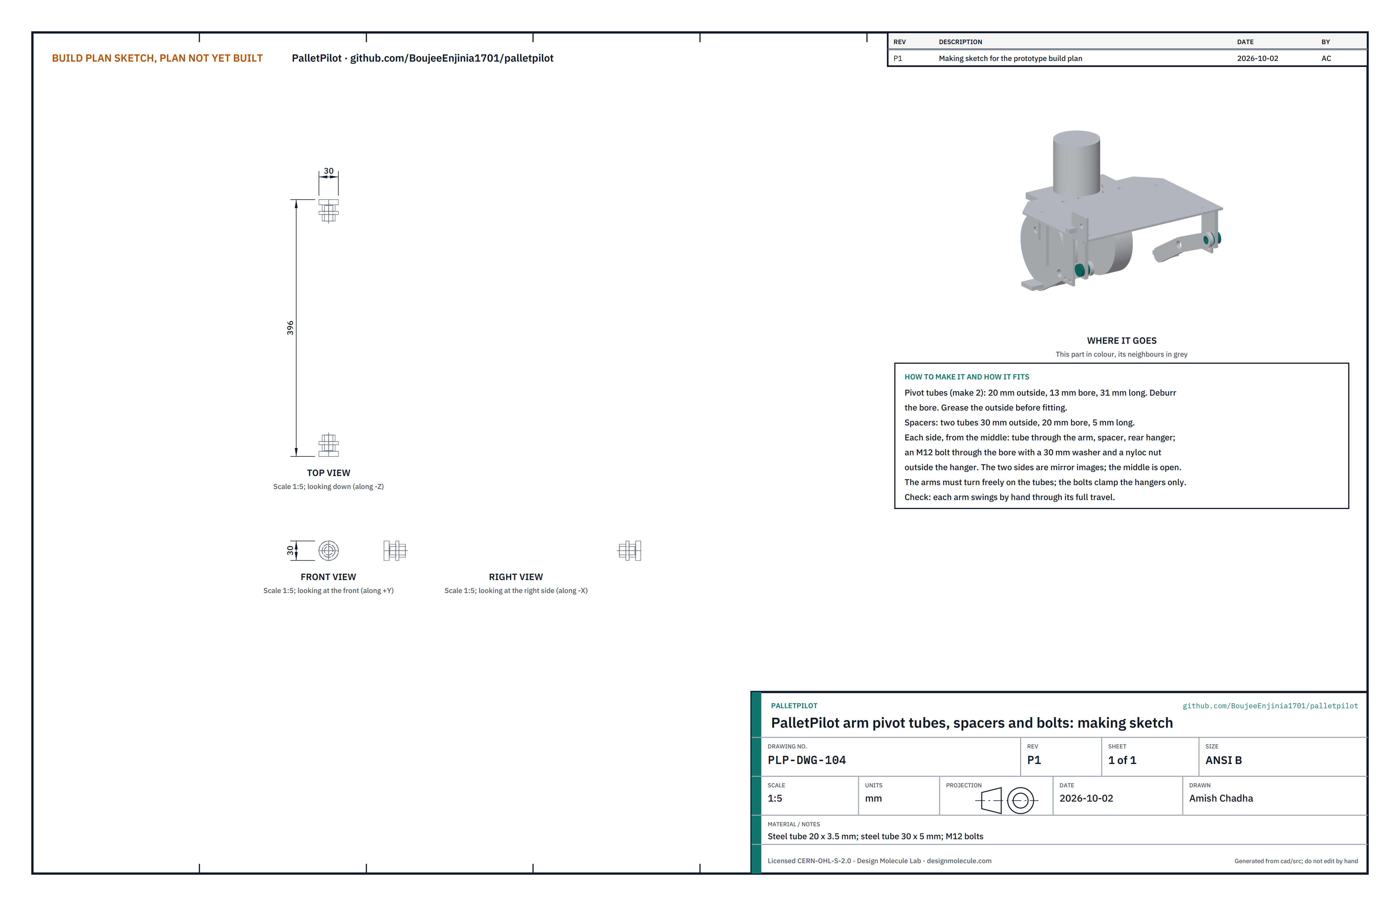
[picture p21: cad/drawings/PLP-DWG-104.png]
Figure 9. Making sketch of the pivot tubes


*Figure 9. Pivot tube making sketch (PLP-DWG-104).*

**What it is and what it is made from.** The two short tubes the arms turn on, one for each arm, so the middle of the frame stays open. 20 mm outside, 13 mm bore steel tube; two spacers from 30 x 5 tube; two M12 bolts, each with a 30 mm washer and a nyloc nut.

**How to make it.**

1. Cut two pivot tubes 31 long from the 20 mm tube and deburr the bores.
2. Cut two spacers 5 long from 30 mm tube with a 20 mm bore; deburr.

**How it fits the parts next to it.**

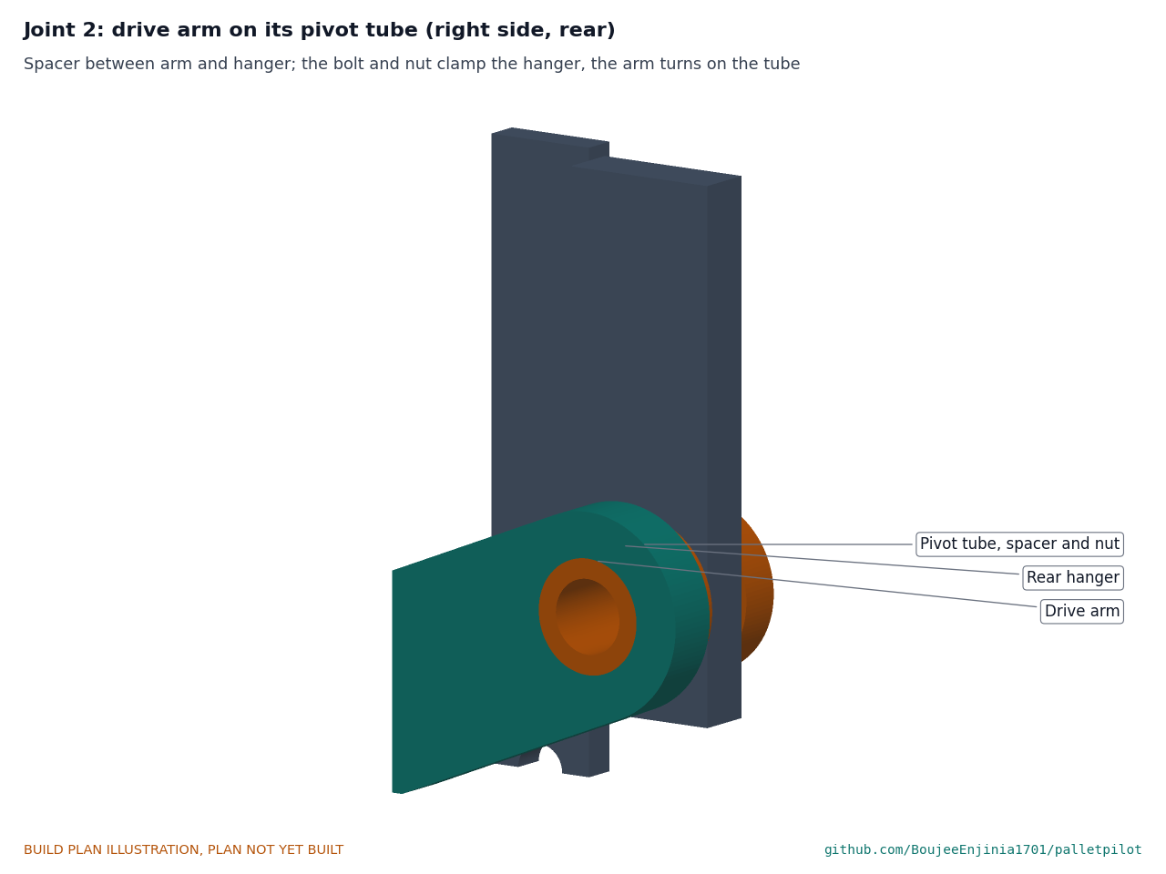
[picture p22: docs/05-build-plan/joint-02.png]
Figure 10. Joint 2: drive arm on its pivot tube


*Figure 10. Each arm turns on its tube between a spacer and the open middle; the bolt and nut clamp the hanger, not the arm.*

**Check before moving on.** Each arm swings freely by hand on its greased tube.

### 3.8 Springs, spring saddles and lift straps

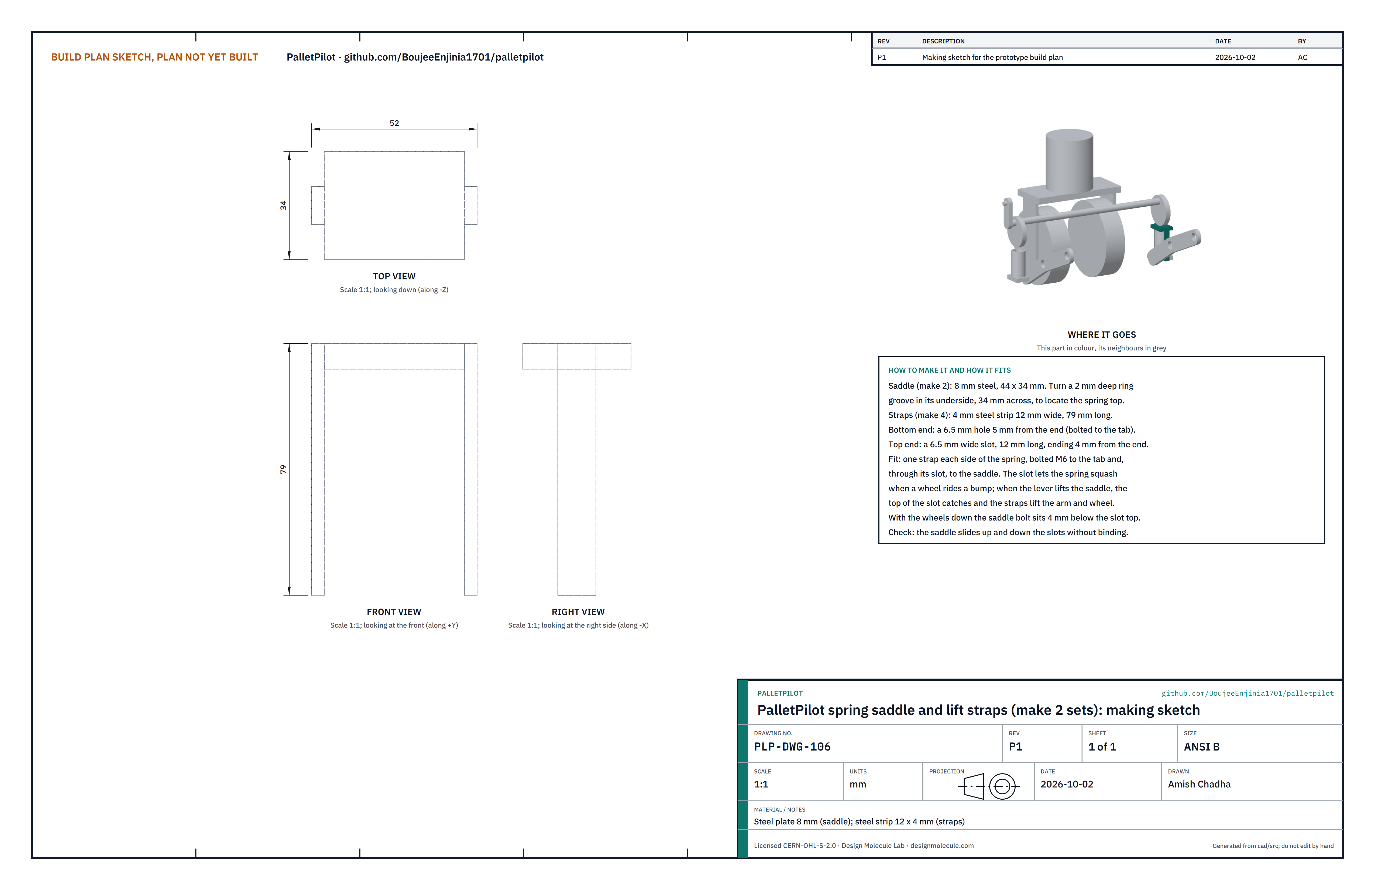
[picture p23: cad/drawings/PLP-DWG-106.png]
Figure 11. Making sketch of the saddle and straps


*Figure 11. Spring saddle and lift straps making sketch (PLP-DWG-106).*

**What it is and what it is made from.** Each drive arm's spring stands on the arm's tab; a steel saddle sits on top of it, under the cam. Two slotted straps join each saddle to its tab, so that raising the saddle lifts the arm. Springs are bought: compression springs about 34 outside diameter, about 65 free length, about 100 N/mm. Saddles from 8 mm steel; straps from 12 x 4 strip.

**How to make it.**

1. Cut two saddles 44 x 34. Turn or mill a ring groove 2 deep and 34 across in the underside to locate the spring. Drill and tap M6 into the middle of its front and back edges (the 34 long ones).
2. Cut four straps 79 long. Drill a 6.5 mm hole 5 from one end; at the other end cut a slot 6.5 wide and 12 long, ending 4 from the end.

**How it fits the parts next to it.**

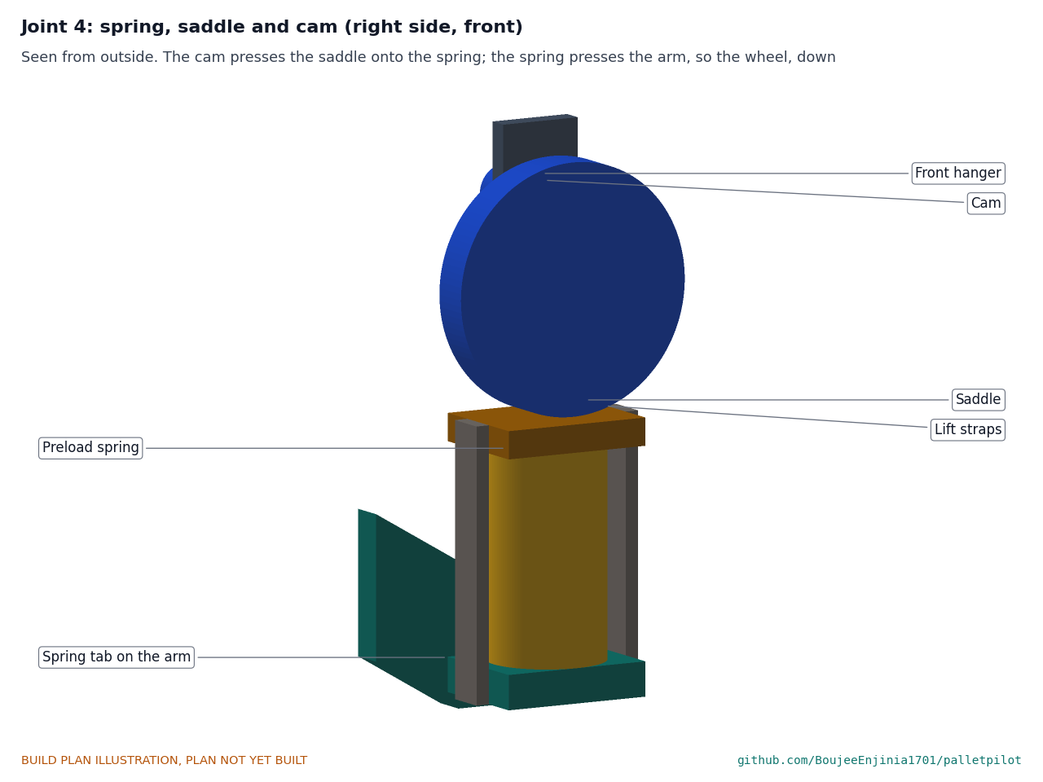
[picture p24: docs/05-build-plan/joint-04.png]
Figure 12. Joint 4: spring, saddle and cam


*Figure 12. The cam presses the saddle down onto the spring, and the spring presses the arm, and so the wheel, onto the floor.*

Each spring is squashed about 4 by the cam when the wheels are down, which puts about 420 N on each arm's tab and 750 N on each wheel. Each strap is bolted M6 to the tab through its hole and to the saddle through its slot, with the saddle bolt 4 below the top of the slot when the wheels are down. A bump can squash the spring further; when the lever is raised, the saddle rises, the slot's top catches the bolt, and the straps lift the arm.

**Check before moving on.** The saddle slides up and down in the slots without binding.

### 3.9 Release lever and link

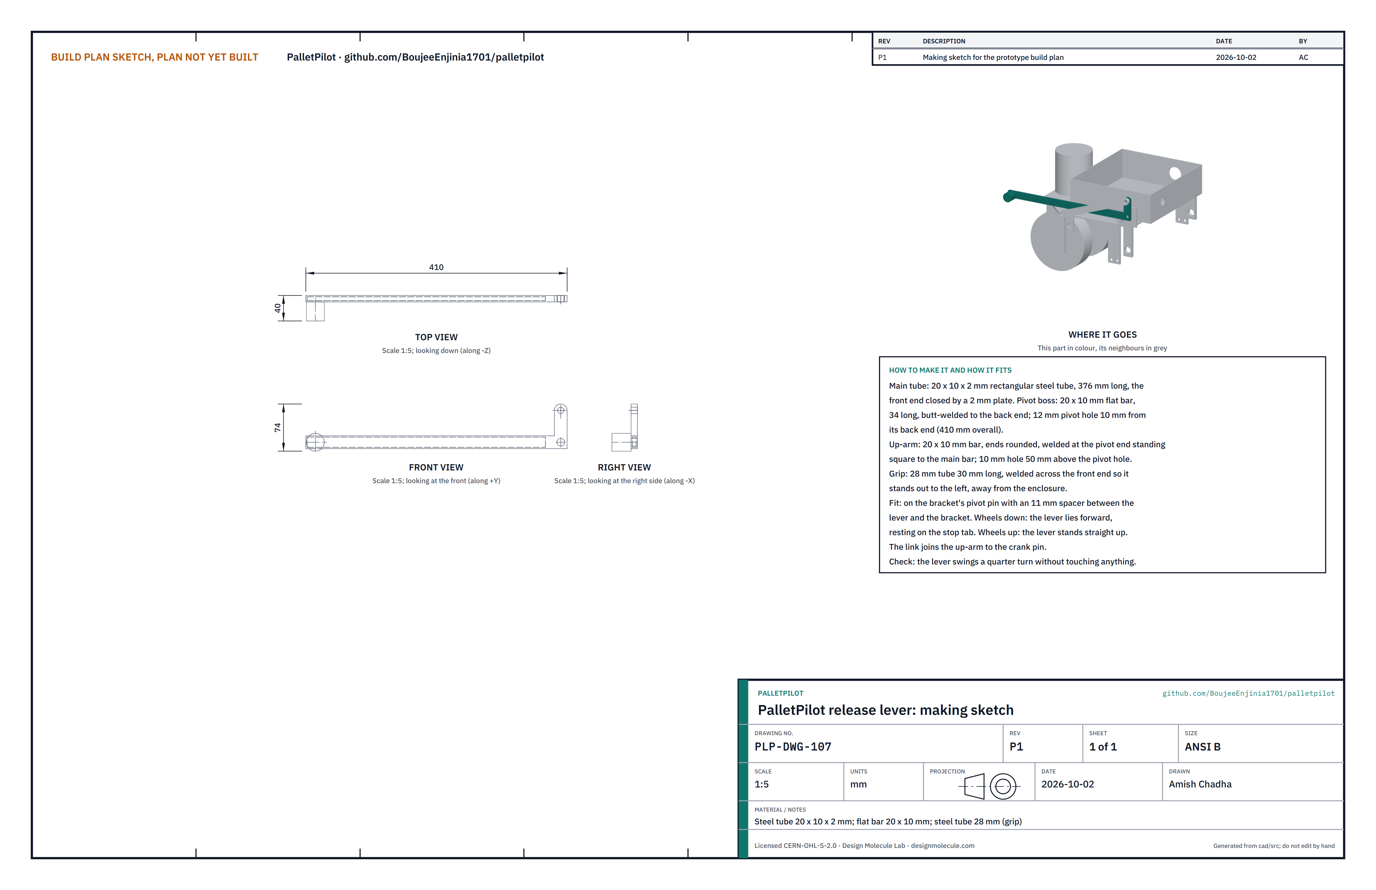
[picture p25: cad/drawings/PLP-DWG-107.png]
Figure 13. Making sketch of the release lever


*Figure 13. Release lever making sketch (PLP-DWG-107).*

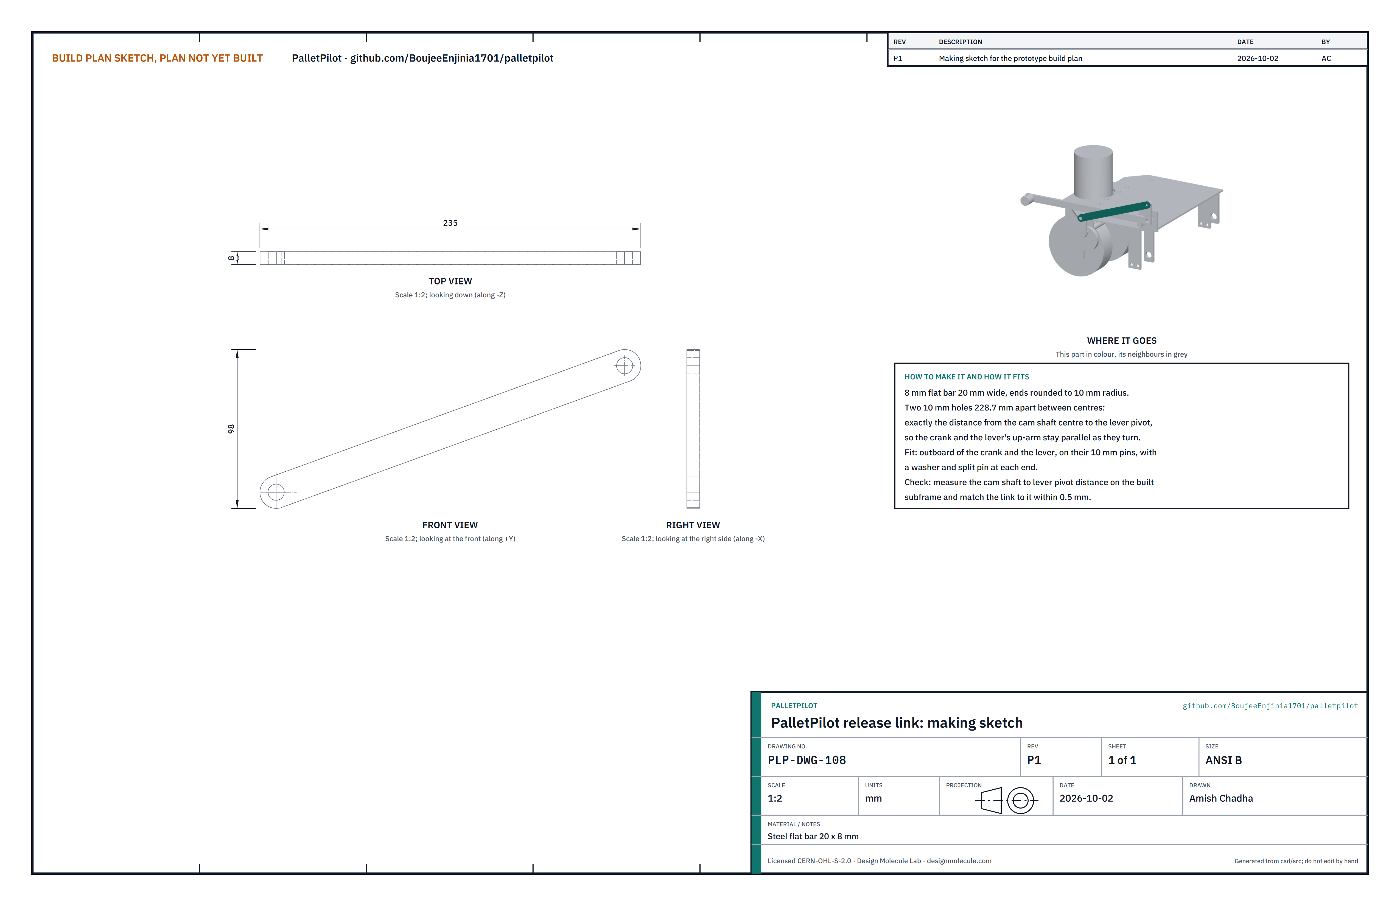
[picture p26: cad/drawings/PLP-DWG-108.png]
Figure 14. Making sketch of the release link


*Figure 14. Release link making sketch (PLP-DWG-108).*

**What it is and what it is made from.** The lever on the left of the enclosure that lifts the drive wheels for pushing by hand, and the link that joins it to the cam shaft's crank. It lifts the wheels about 10 mm, so the release is for smooth indoor floors only (PLP-DEC-001). A 20 x 10 x 2 steel tube with a flat bar boss and a 28 mm tube grip; link from 20 x 8 flat bar.

**How to make it.**

1. Lever: cut the main tube 376 long from 20 x 10 x 2 rectangular tube and cap its front end with a 2 mm plate. Cut a 34 long boss from 20 x 10 flat bar, drill a 12 mm pivot hole 10 from its end, and butt-weld it to the tube's back end. Cut the up-arm from flat bar, round its ends, drill a 10 mm hole 50 from the pivot hole centre, and weld it at the pivot end, square to the main bar. Weld a 30 long piece of 28 mm tube across the far end as a grip, standing out to the left.
2. Link: measure the distance from the cam shaft's centre to the lever bracket's pivot hole on your subframe (228.7 on the drawing). Cut the link and drill its two 10 mm holes exactly that distance apart, within 0.5.
3. Make the lever's pivot pin (12 mm, 27 long, with a split pin hole) and an 11 long spacer of 20 mm tube.

**How it fits the parts next to it.**

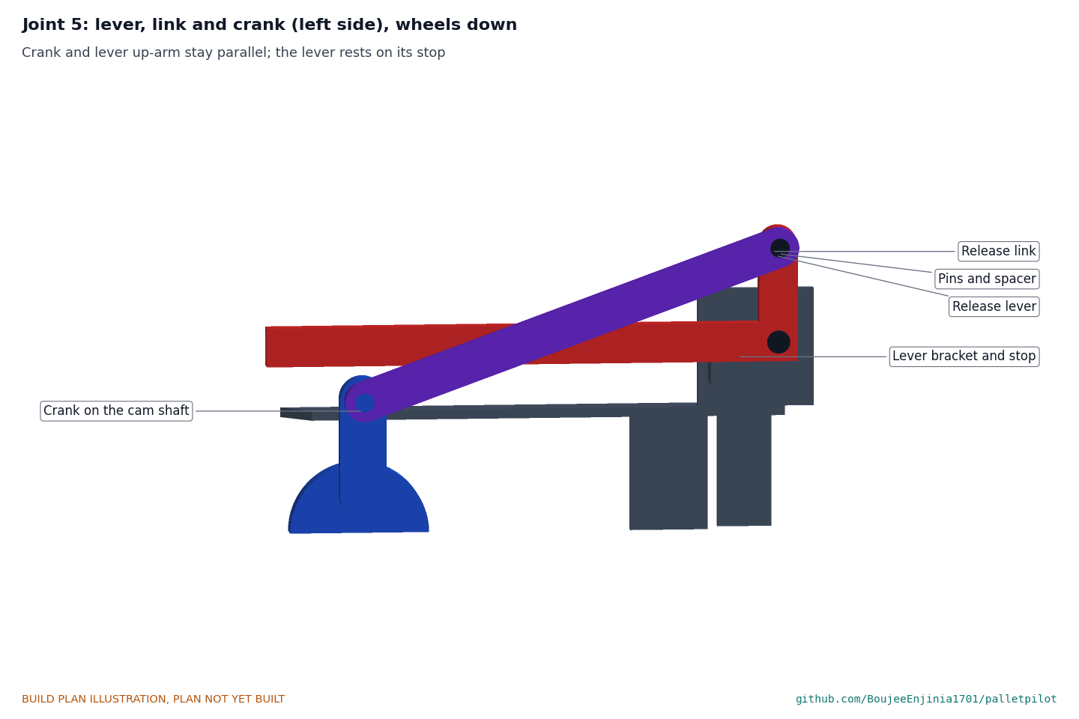
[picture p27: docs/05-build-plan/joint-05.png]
Figure 15. Joint 5: lever, link and crank, wheels down


*Figure 15. The crank and the lever's up-arm stay parallel through the link; with the wheels down the lever lies forward on its stop.*

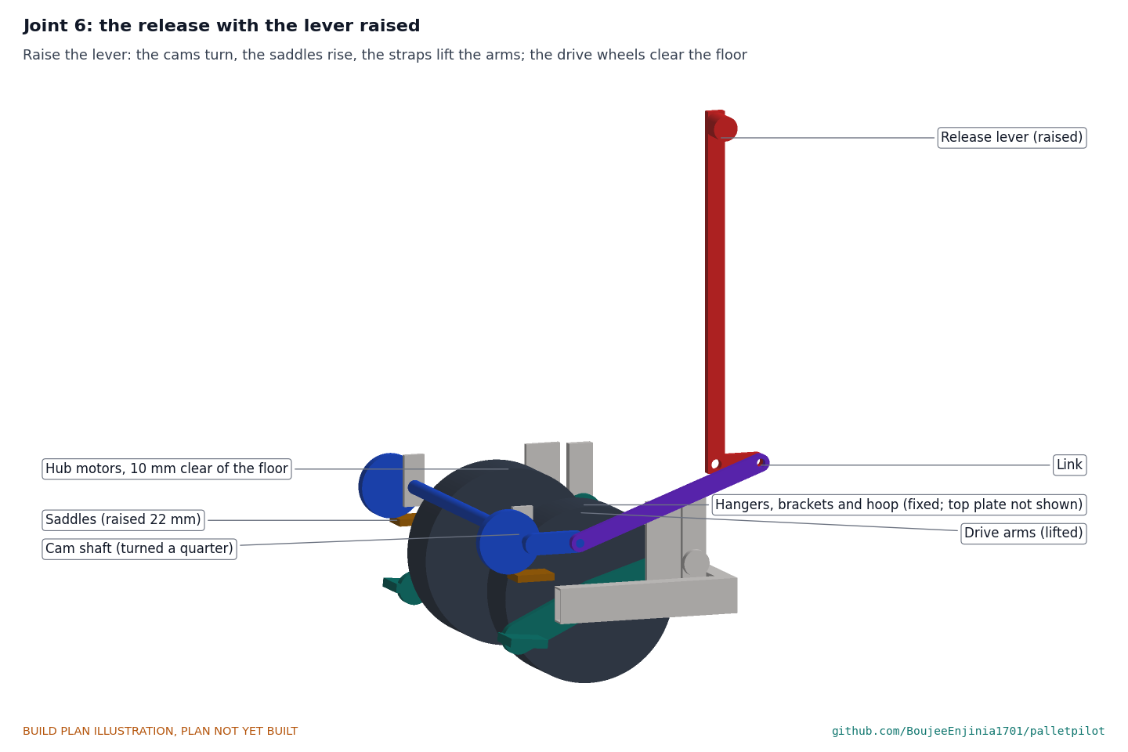
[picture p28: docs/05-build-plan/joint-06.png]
Figure 16. Joint 6: the release with the lever raised


*Figure 16. Raising the lever a quarter turn turns the cams, lifts the saddles 22 and, through the straps, lifts both drive wheels about 10 clear of the floor.*

The lever turns on its pin in the bracket with the spacer between them. The link sits outboard of the crank and the up-arm, on their 10 mm pins, with a washer and split pin at each end. With the wheels down, the cams are just past their lowest point and the springs hold the lever down on its stop, so it cannot creep up. The peak effort to raise it is about 58 N at the grip.

**Check before moving on.** The lever swings a quarter turn without touching the enclosure or the hoop.

### 3.10 Enclosure, lid and feet

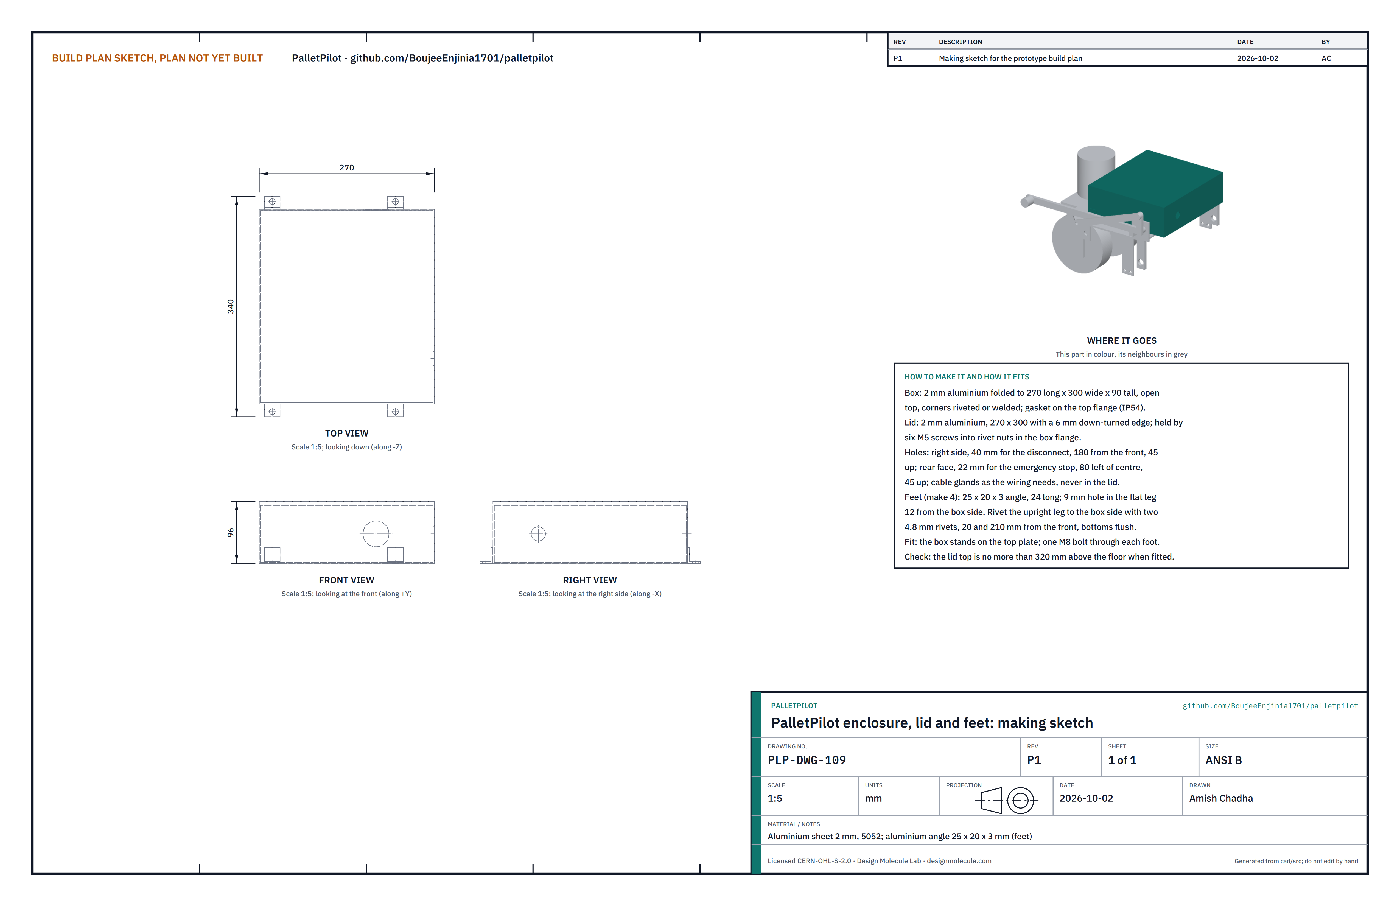
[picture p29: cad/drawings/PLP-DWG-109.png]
Figure 17. Making sketch of the enclosure


*Figure 17. Enclosure, lid and feet making sketch (PLP-DWG-109).*

**What it is and what it is made from.** The low box that holds the battery and electronics, under the jack's handle. 2 mm aluminium sheet, 5052 class; feet from 25 x 20 x 3 aluminium angle.

**How to make it.**

1. Have the box folded from 2 mm sheet to 270 long, 300 wide and 90 tall, open at the top with an inward flange for the lid gasket; rivet or weld the corners.
2. Fold the lid to 270 x 300 with a 6 mm down-turned edge. Fit six M5 rivet nuts in the box flange and drill the lid to match.
3. Cut holes: 40 mm on the right side for the disconnect, 180 from the front end and 45 up; 22 mm in the back face for the emergency stop, 80 left of centre and 45 up; and glands for the cables as the wiring needs. Never put a hole in the lid.
4. Cut four feet 24 long from the angle and drill a 9 mm hole in each flat leg, 12 from the upright leg. Rivet each upright leg to the box side with two 4.8 mm rivets, 20 and 210 from the front end, bottoms flush with the box bottom.

**How it fits the parts next to it.**

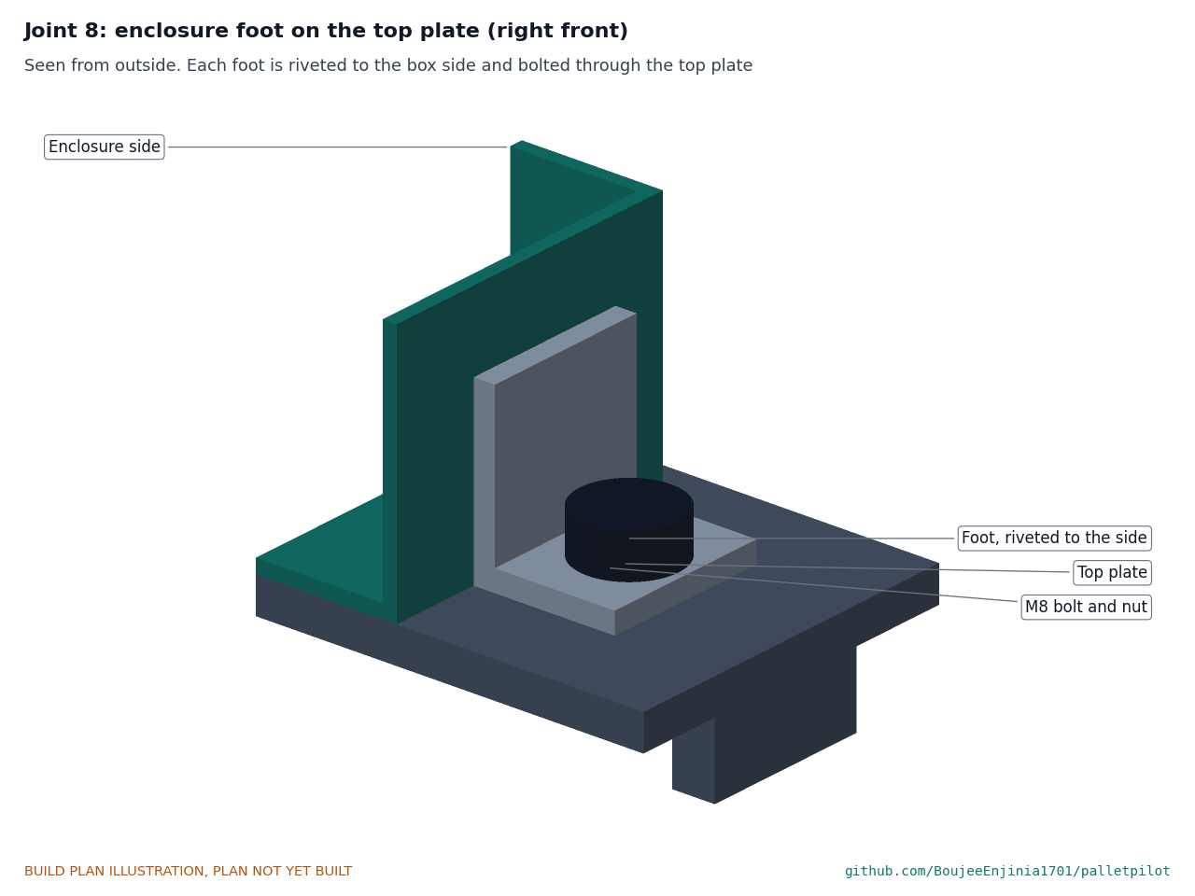
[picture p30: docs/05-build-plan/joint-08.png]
Figure 18. Joint 8: enclosure foot on the top plate


*Figure 18. Each foot is riveted to the box side and held to the top plate by one M8 bolt, nut below.*

**Check before moving on.** The lid seals on its gasket all round; with the box on the top plate, the lid top is 320 or less above the floor, so the lowered handle clears it by 14.

#### 3.10.1 Electrical parts and wiring

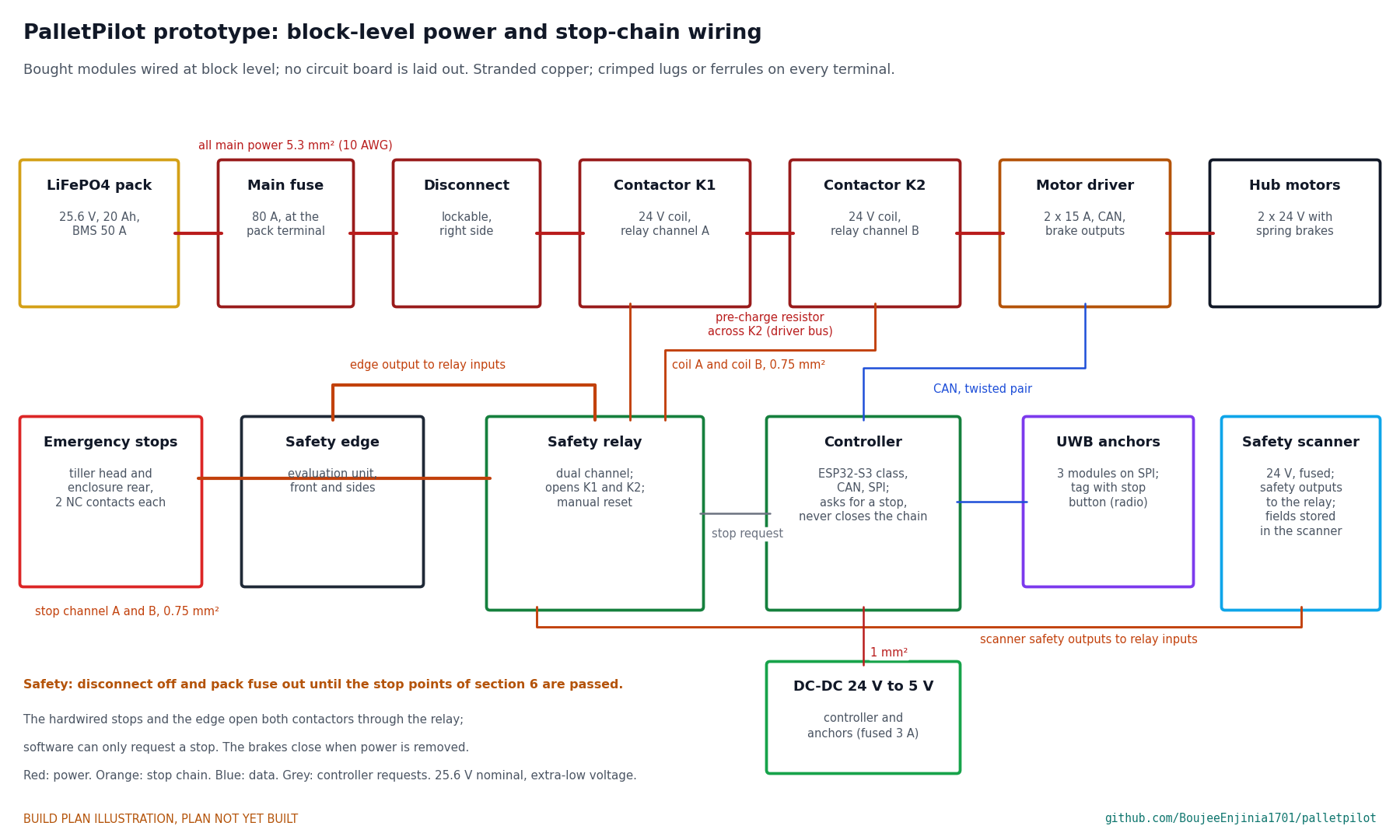
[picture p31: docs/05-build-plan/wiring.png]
Figure 19. Block-level power and stop-chain wiring


*Figure 19. Block-level wiring. No circuit board is laid out at this stage; bought modules are wired together.*

*Table 2. Electrical modules (bill of materials lines 4 to 7, 9, 11, 14, 16 to 18).*

| Module | What to buy |
| --- | --- |
| Battery | 8S LiFePO4, 25.6 V, 20 Ah, about 270 x 115 x 85, with a BMS rated 50 A continuous and a charge temperature cut-off below 0 °C |
| Main fuse and disconnect | 80 A fuse at the battery terminal; lockable battery disconnect for panel mounting |
| Contactors | Two 24 V main contactors rated 80 A or more, with a pre-charge resistor for the driver's input capacitors |
| Motor driver | Dual-channel 24 V brushless servo driver, 2 x 15 A continuous, 30 A peak, CAN, brake outputs, safe torque off and a monitored controlled-stop input, matched to the motors' encoders |
| Controller and safety relay | ESP32-S3 class controller with a CAN transceiver; dual-channel safety relay with manual reset |
| Stop devices | Two 22 mm emergency stops with two normally closed contacts each; the safety edge's evaluation unit |
| Sensors | Safety laser scanner (Type 3, PL d, 3 m protective field, 70 ms response, about 107 x 80 x 118, 0.67 kg; mounted on the hoop, section 3.12); three UWB anchor modules (DWM3000 class); Hall angle sensor on the handle pivot |

Wire it as Figure 19 shows. All main power is 5.3 mm² (10 AWG) with crimped lugs; stop-chain and coil wiring 0.75 mm²; signals in twisted pairs. Both emergency stops and the safety edge feed the safety relay's two channels; each channel opens one contactor. The controller can only ask the relay for a stop; it can never close the chain. The motor brakes close when power is removed.

**Check before moving on.** With the battery fuse out: every wire continues end to end and is labelled; pressing either emergency stop or the edge opens both relay channels (meter on each coil circuit).

### 3.11 Bumper hoop

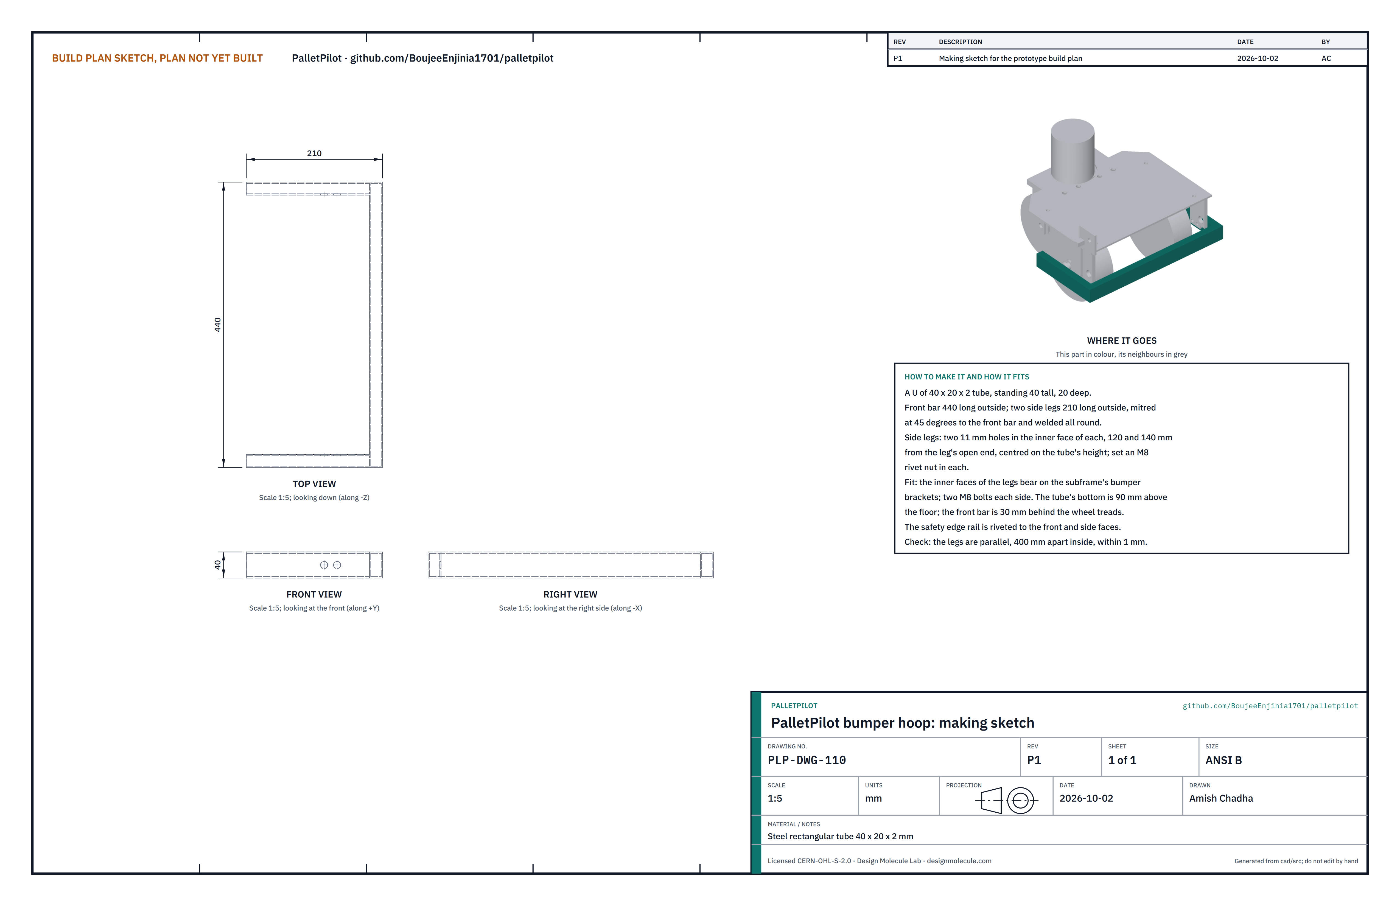
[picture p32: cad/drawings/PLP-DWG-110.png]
Figure 20. Making sketch of the bumper hoop


*Figure 20. Bumper hoop making sketch (PLP-DWG-110).*

**What it is and what it is made from.** A U of steel tube round the drive end that carries the safety edge. 40 x 20 x 2 rectangular tube, standing 40 tall.

**How to make it.**

1. Cut the front bar 440 long and two side legs 210 long, outside lengths, with 45° mitres at the corners. Weld all round and grind the corners smooth.
2. In the inner face of each leg drill two 11 mm holes, 120 and 140 from the leg's open end, centred on the tube's height, and set an M8 rivet nut in each.
3. In the top of the front bar, on the centre line, drill and set two M5 rivet nuts, 30 apart, for the scanner shelf, and two at each front corner for the anchor plates.
4. Paint safety yellow.

**How it fits the parts next to it.**

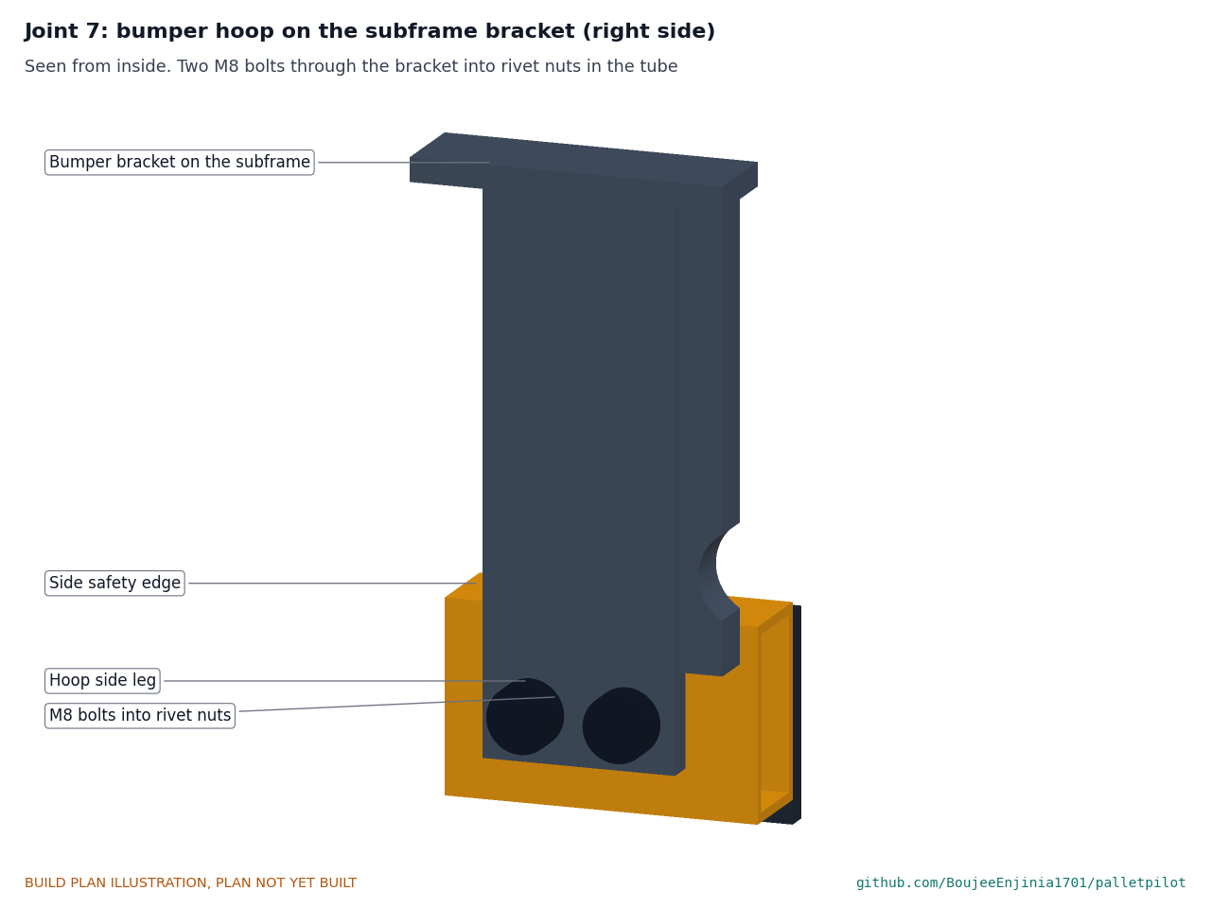
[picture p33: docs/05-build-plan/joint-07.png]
Figure 21. Joint 7: the hoop on the subframe bracket, seen from inside


*Figure 21. Each leg's inner face bears on the subframe's bumper bracket; two M8 bolts go through the bracket into the rivet nuts.*

The tube's underside is 90 above the floor and the front bar is 30 behind the drive wheels' treads. The safety edge's rail is riveted to the front face (the 50 deep front edge, 40 travel) and to the outer faces of both legs (20 deep).

**Check before moving on.** The legs are parallel and 400 apart inside, within 1.

### 3.12 Scanner shelf

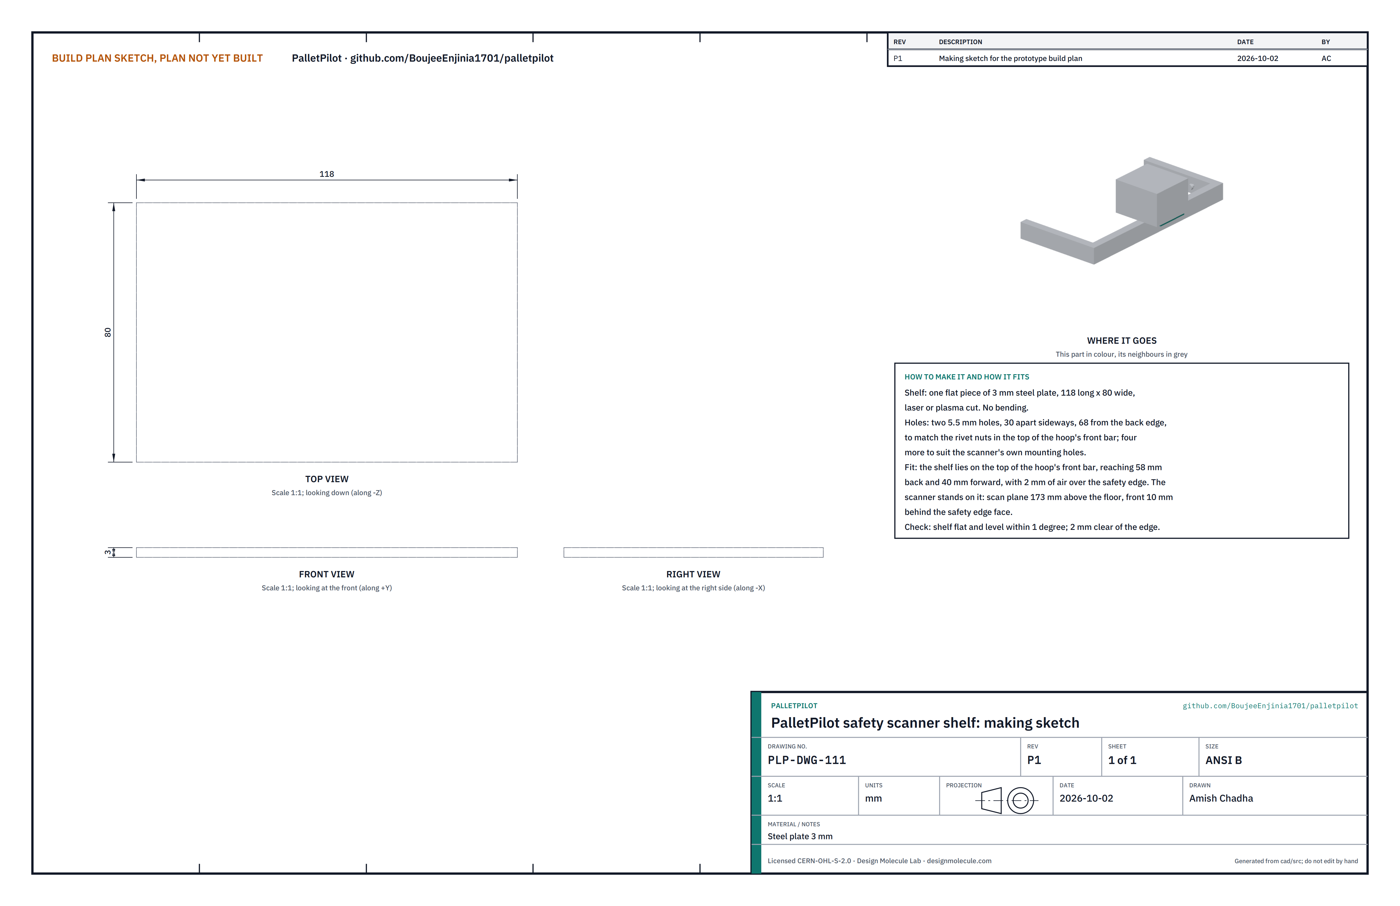
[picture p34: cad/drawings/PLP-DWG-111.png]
Figure 22. Making sketch of the scanner shelf


*Figure 22. Scanner shelf making sketch (PLP-DWG-111).*

**What it is and what it is made from.** A flat shelf that holds the safety scanner just behind the bumper face. 3 mm steel plate.

**How to make it.**

1. Have the shelf laser or plasma cut from 3 mm plate, 118 long and 80 wide. It is not bent.
2. Drill two 5.5 mm holes, 30 apart sideways and 68 from the back edge, to match the rivet nuts in the hoop's front bar, and four more to suit the scanner's own mounting holes.

**How it fits the parts next to it.**

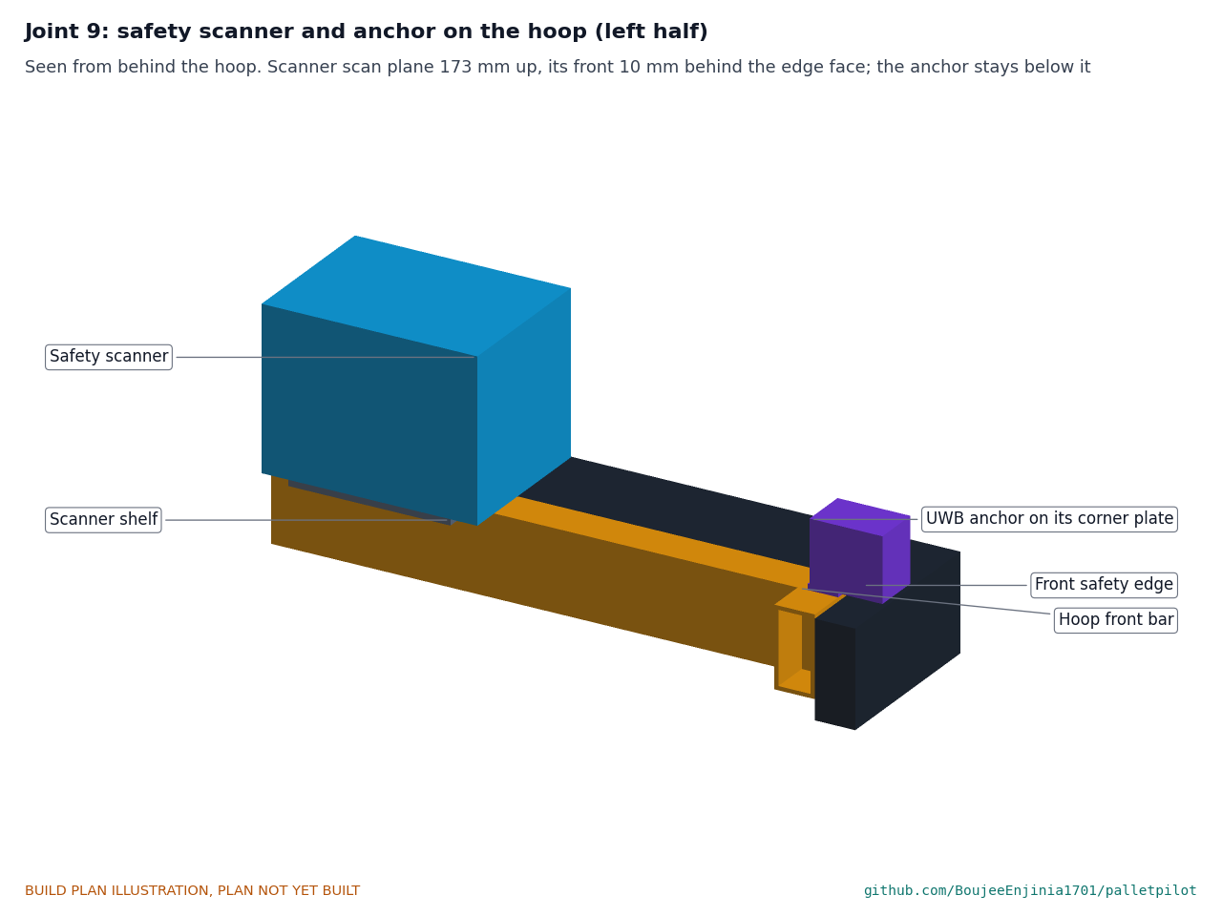
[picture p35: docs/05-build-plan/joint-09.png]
Figure 23. Joint 9: scanner and anchor on the hoop


*Figure 23. The scanner's scan plane is 173 above the floor and its front 10 behind the bumper face; the shelf reaches back and forward from the hoop's front bar with 2 of air over the safety edge; each anchor sits on a corner plate below the scan plane.*

**Check before moving on.** The shelf is flat and level within 1° both ways and 2 clear of the safety edge.

### 3.13 Bought components

Buy to specification, not brand. Line numbers are those of the bill of materials.

- **Hub motors (line 2).** As section 3.5; confirm the 24 V winding, the brake's holding torque (20 N·m or more) and the shaft's size and flats before the arms are cut.
- **Springs (line 13).** Two compression springs, about 34 outside diameter, 65 free length, 100 N/mm, closed and ground ends.
- **Steering stops (line 19).** As section 3.2.
- **Battery, driver, contactors, controller, relay and stops (lines 4 to 7 and 9).** As Table 2.
- **Tiller head (line 8).** A clamp-on walkie head that fits the jack's handle tube, with a thumbwheel throttle, belly-reverse paddle, mode key, horn and a beacon mount; carries the beacon (line 12), the second emergency stop and the third UWB anchor.
- **Safety edge (line 10).** Pressure-sensitive edge with its evaluation unit and an aluminium mounting rail: front length 480 with 40 or more of travel, two side lengths of about 210.
- **UWB anchors (line 11) and safety scanner (line 18).** As Table 2; the scanner's safety outputs go to the safety relay; each anchor in a small box on a corner plate screwed to the hoop.
- **Handle sensor and gas spring (line 16), charger (line 14), operator tag (line 15).** As the bill of materials; the charger and tag are not fitted to the jack.
- **Fixings (line 17).** Four M12 x 50 bolts (8.8) with nuts and hardened washers; M8 bolts, nyloc nuts and rivet nuts; M6 and M5 screws; M5 rivet nuts; 4.8 mm rivets; 5 mm roll pins; split pins; 5.3 mm² cable, lugs, spiral wrap and labels.

## 4. Putting it together

In each picture the parts already fitted are grey and the part being fitted is in colour, with an arrow showing the way it goes in. Steps 1, 2 and 5 are done on the bench; the jack is then chocked on a level floor with its forks lowered.

### Step 1: steering stops under the top plate

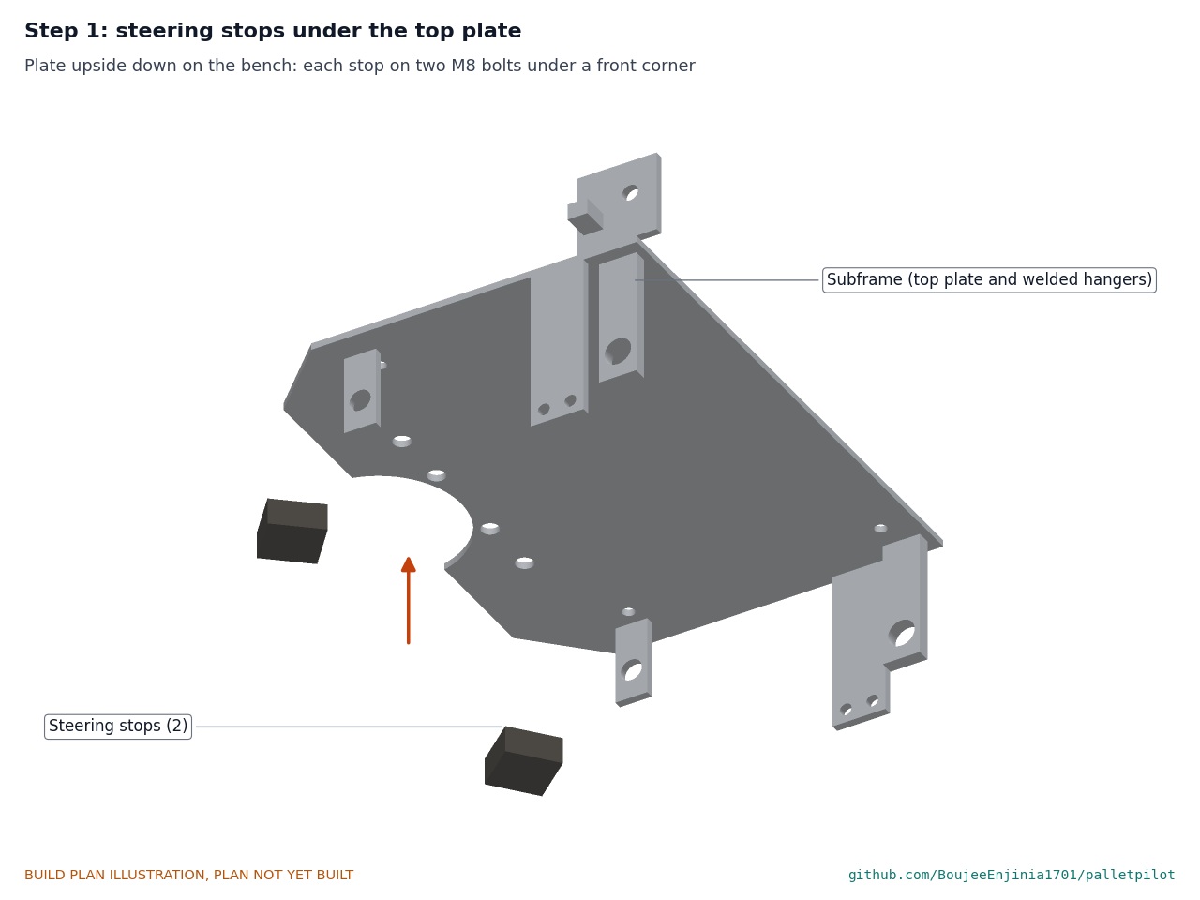
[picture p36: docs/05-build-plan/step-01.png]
Step 1


With the subframe upside down on the bench, bolt each stop under a front corner on two M8 bolts.

### Step 2: cam shaft through the front hangers

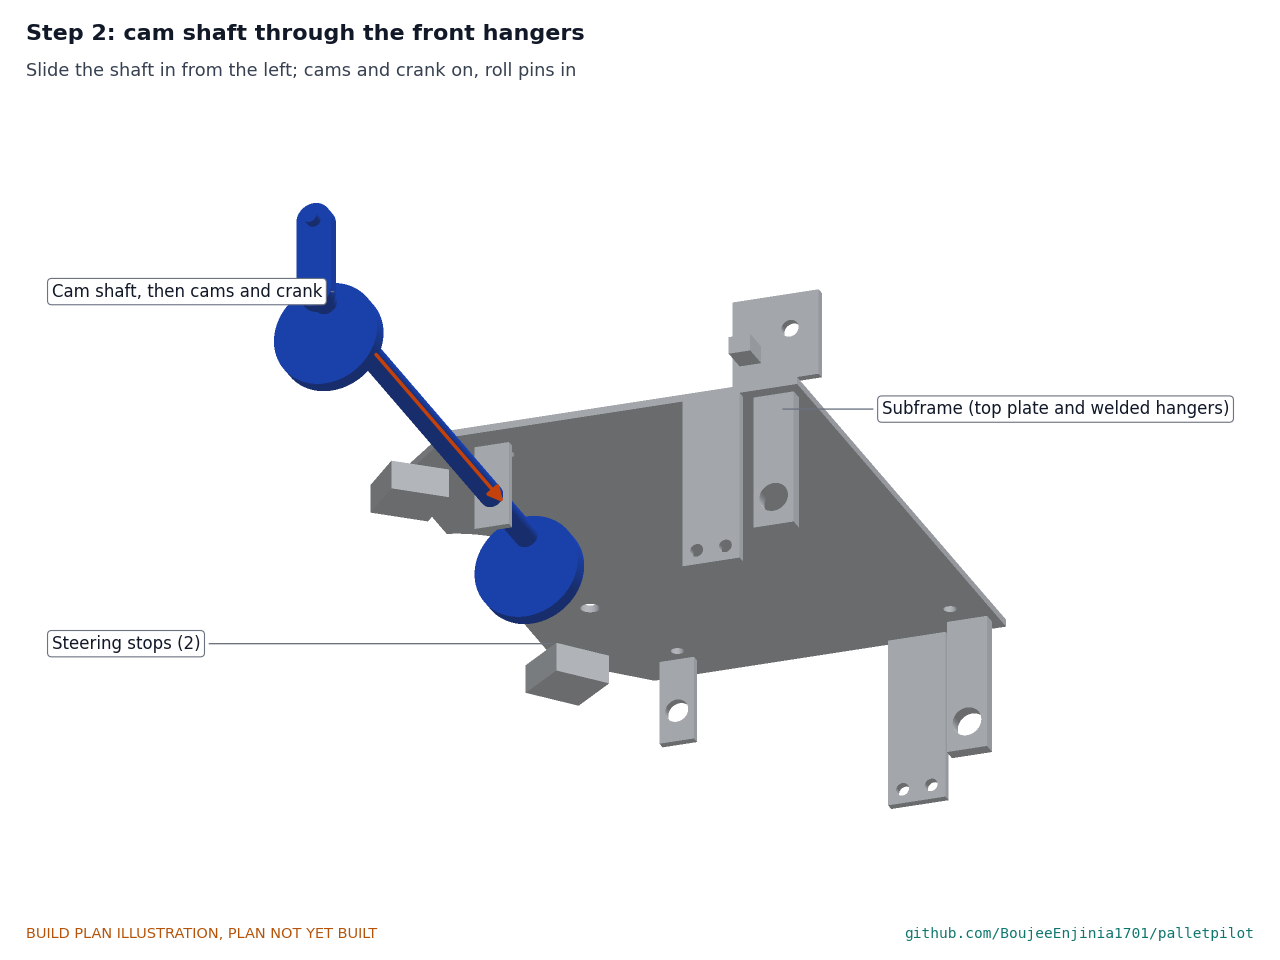
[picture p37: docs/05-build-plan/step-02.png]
Step 2


Slide the shaft in from the left through both front hangers, then fit the cams and the crank and drive in the roll pins as section 3.3.

### Step 3: subframe onto the jack's yoke

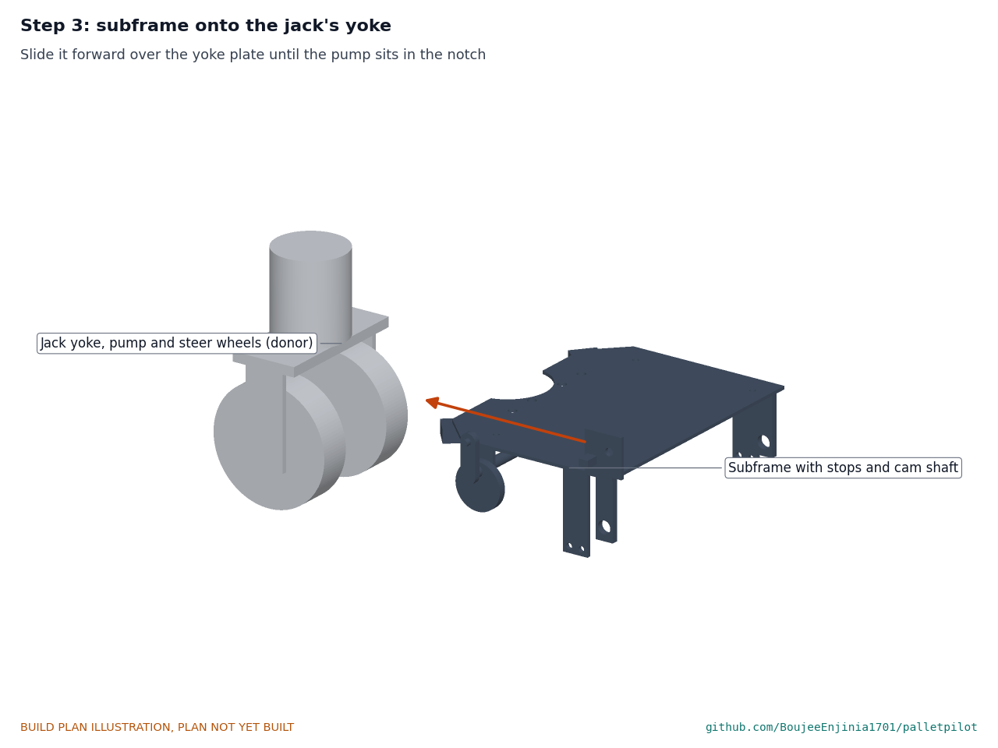
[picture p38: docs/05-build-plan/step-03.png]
Step 3


Remove nothing from the jack. Slide the subframe forward over the yoke plate until the pump sits in the notch and the plate lies flat on the yoke plate.

### Step 4: lower jaw under the yoke plate

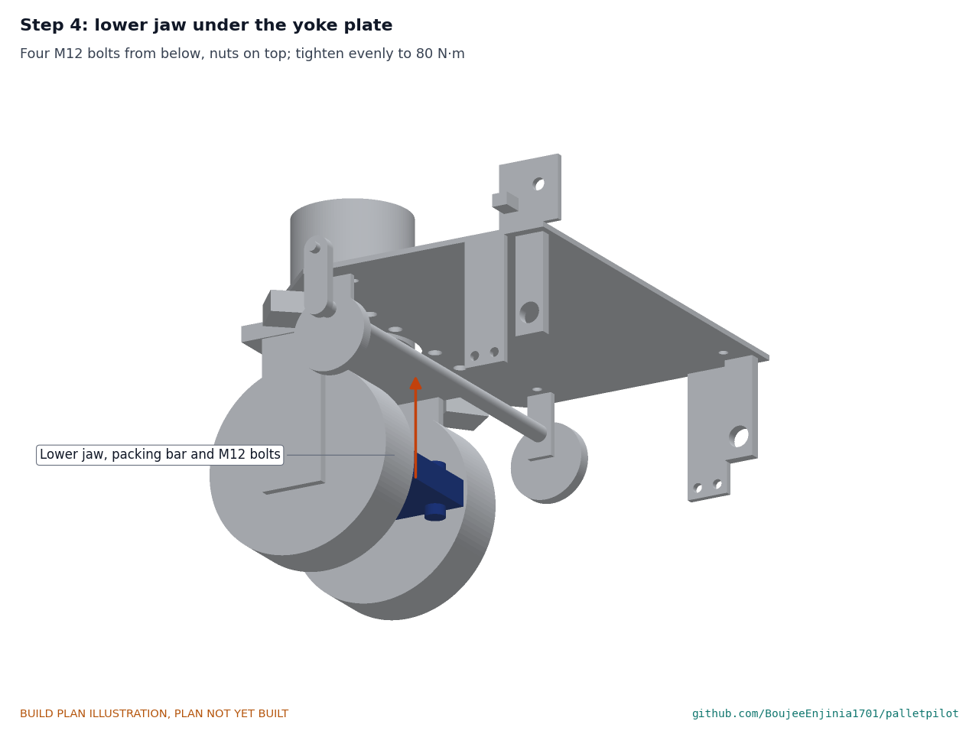
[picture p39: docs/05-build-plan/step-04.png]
Step 4


Offer the jaw up under the yoke plate with the packing bar behind the yoke's edge. Fit the four M12 bolts from below, nuts and hardened washers on top, and tighten evenly in a cross pattern to 80 N·m. **Hold point:** the jaw is flat under the yoke plate and the handle still steers and pumps freely.

### Step 5: hub motors into the drive arms

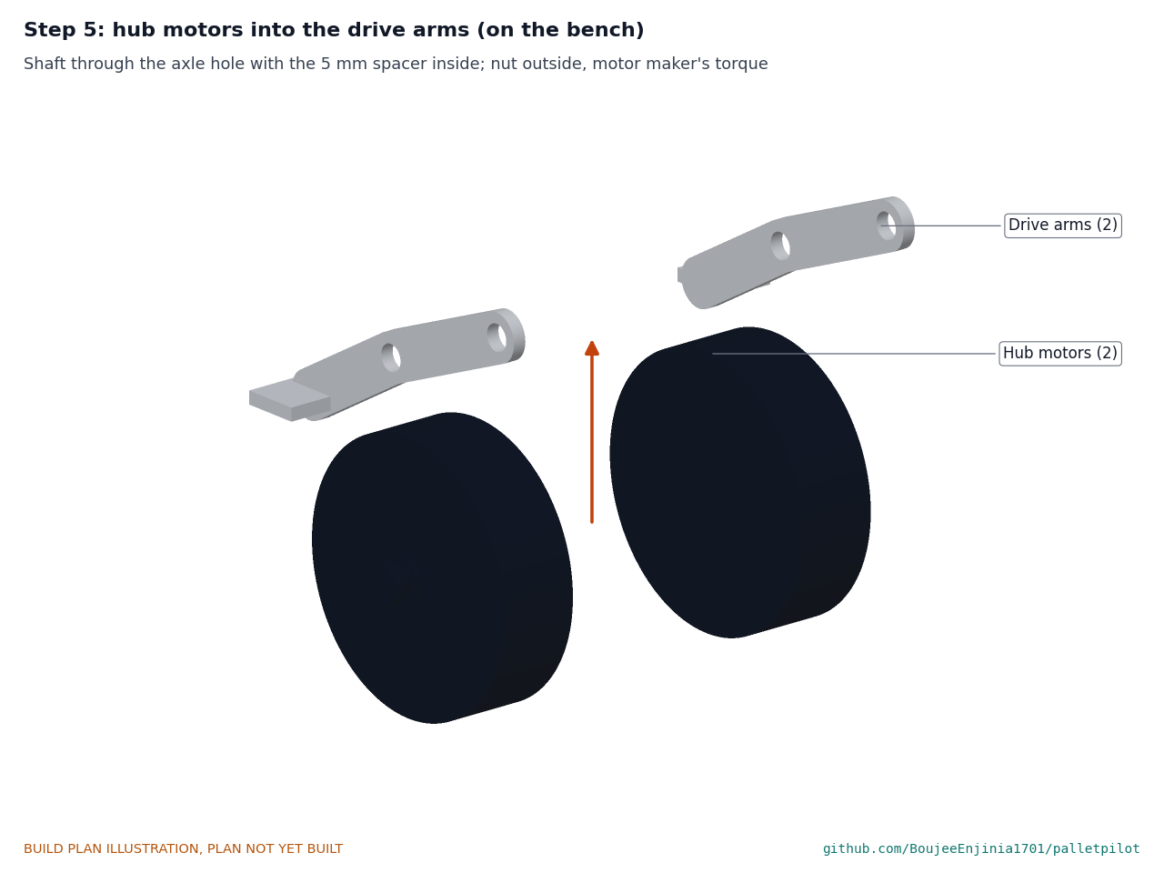
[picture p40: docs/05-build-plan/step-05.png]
Step 5


On the bench, pass each motor's shaft through its arm's axle hole with the 5 mm spacer between motor and arm, and fit the nut outside to the motor maker's torque.

### Step 6: arms and motors onto the pivot tubes

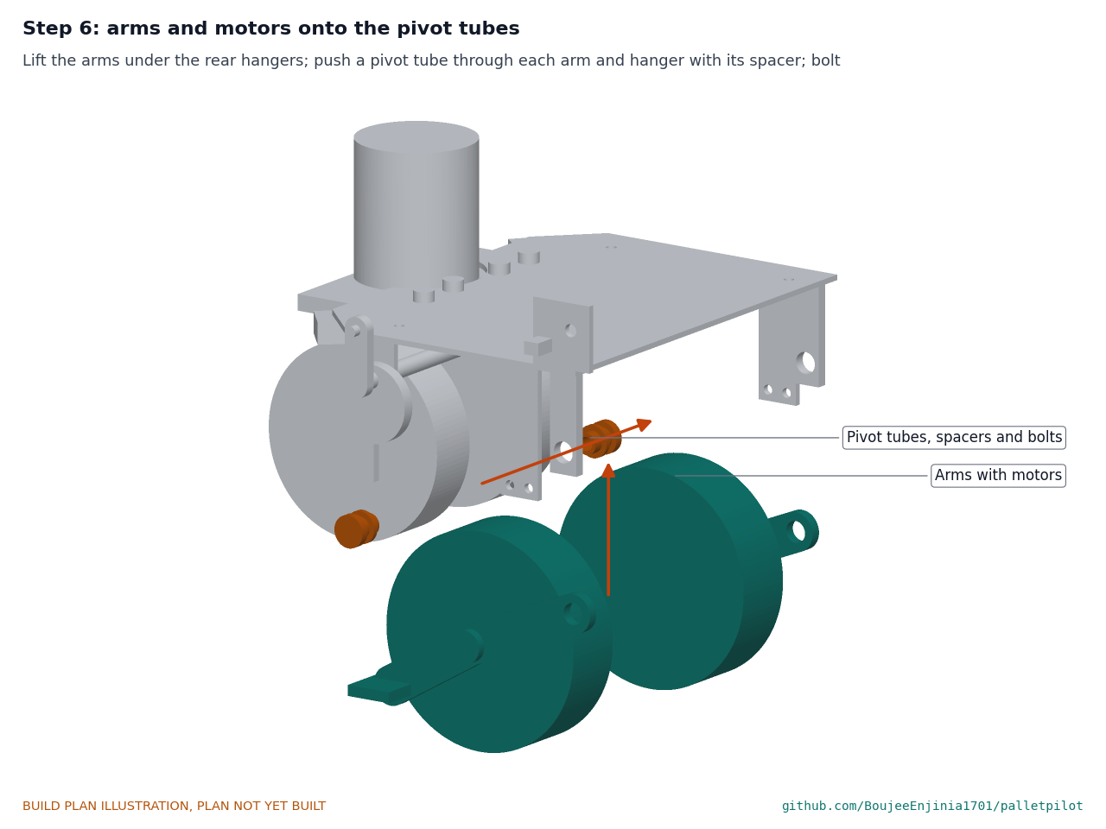
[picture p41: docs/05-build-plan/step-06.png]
Step 6


With a helper, lift both arms with their motors under the subframe so the back holes line up with the rear hangers. On each side, push a greased pivot tube through the arm, a spacer and the hanger, then pass an M12 bolt through the tube's bore and fit its washer and nyloc nut outside the hanger. The wheels rest on the floor.

### Step 7: springs, saddles and lift straps

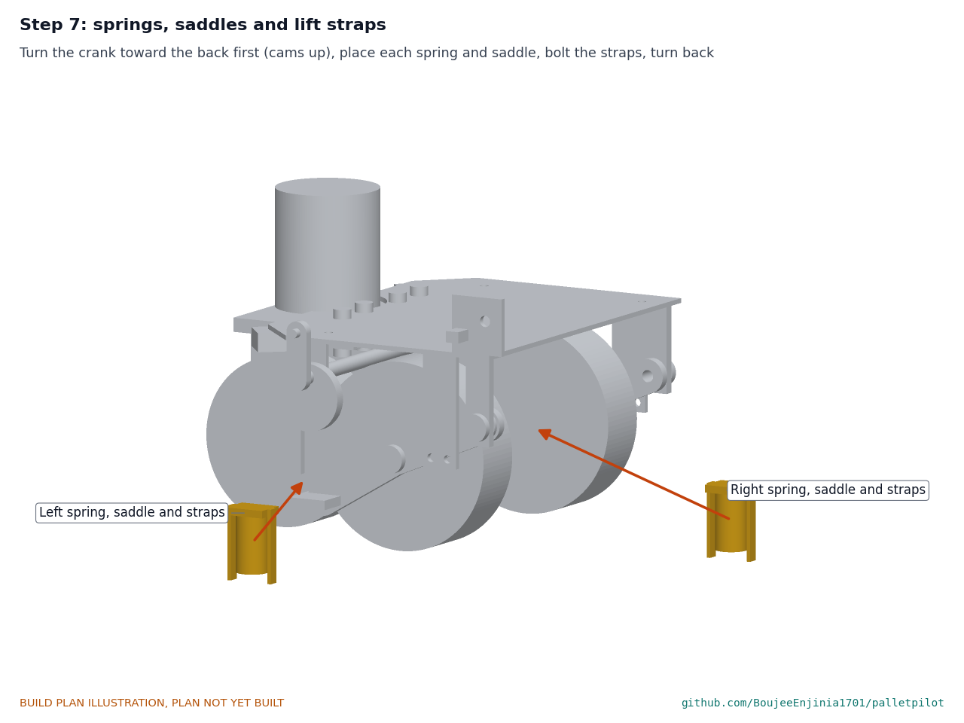
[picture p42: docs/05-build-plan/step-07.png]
Step 7


Turn the crank toward the back of the kit with a spanner, so the cams point their thick side forward and are high. Stand each spring on its tab, put the saddle on top, and bolt the straps to the tab and, through their slots, to the saddle. Turn the crank back upright: the cams press the saddles down and squash the springs about 4.

### Step 8: release lever and link

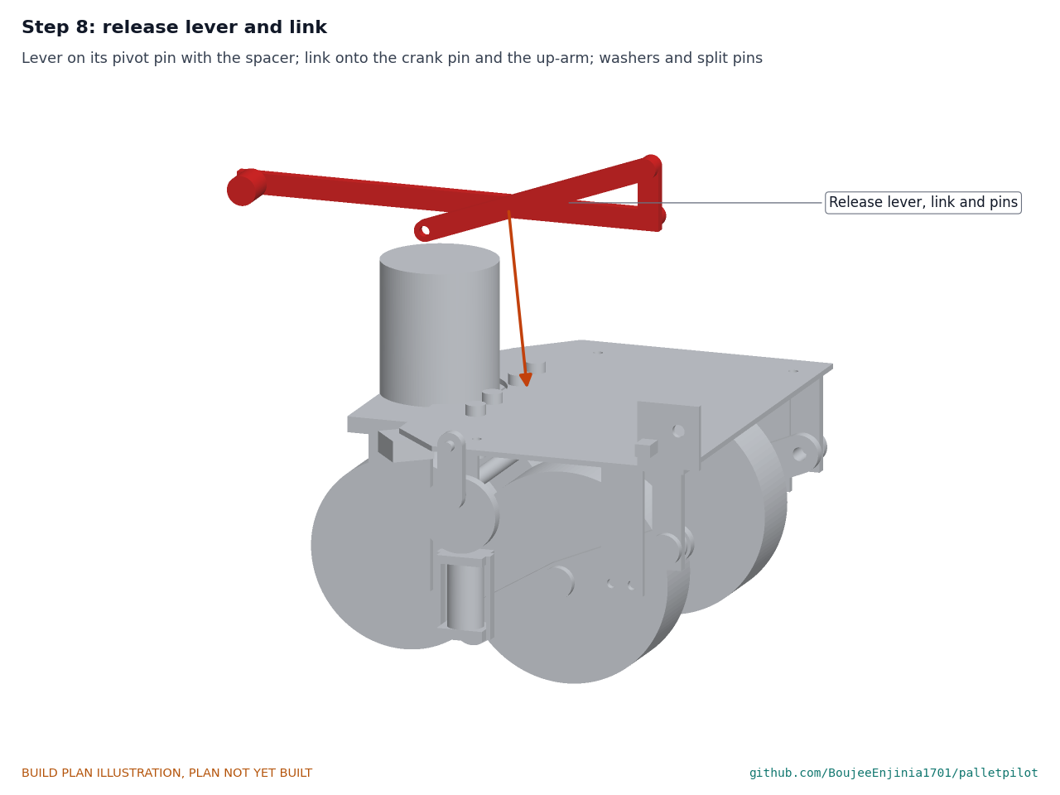
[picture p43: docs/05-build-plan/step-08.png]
Step 8


Fit the lever on its pin in the bracket with the spacer between them. Fit the link over the crank pin and the up-arm's pin, outboard of both, with washers and split pins. **Hold point:** raising the lever lifts both wheels clear of the floor, and lowering it puts them back down with the lever resting on its stop.

### Step 9: enclosure onto the top plate

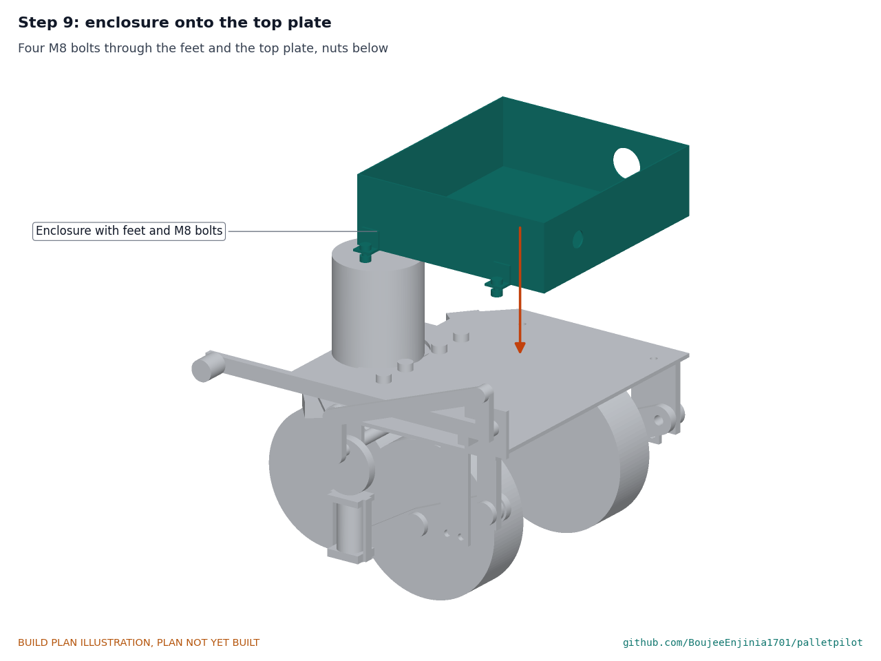
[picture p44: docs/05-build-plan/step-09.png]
Step 9


Stand the box on the top plate and fit one M8 bolt through each foot and the plate, nyloc nut below.

### Step 10: battery, driver, contactors and controller into the enclosure

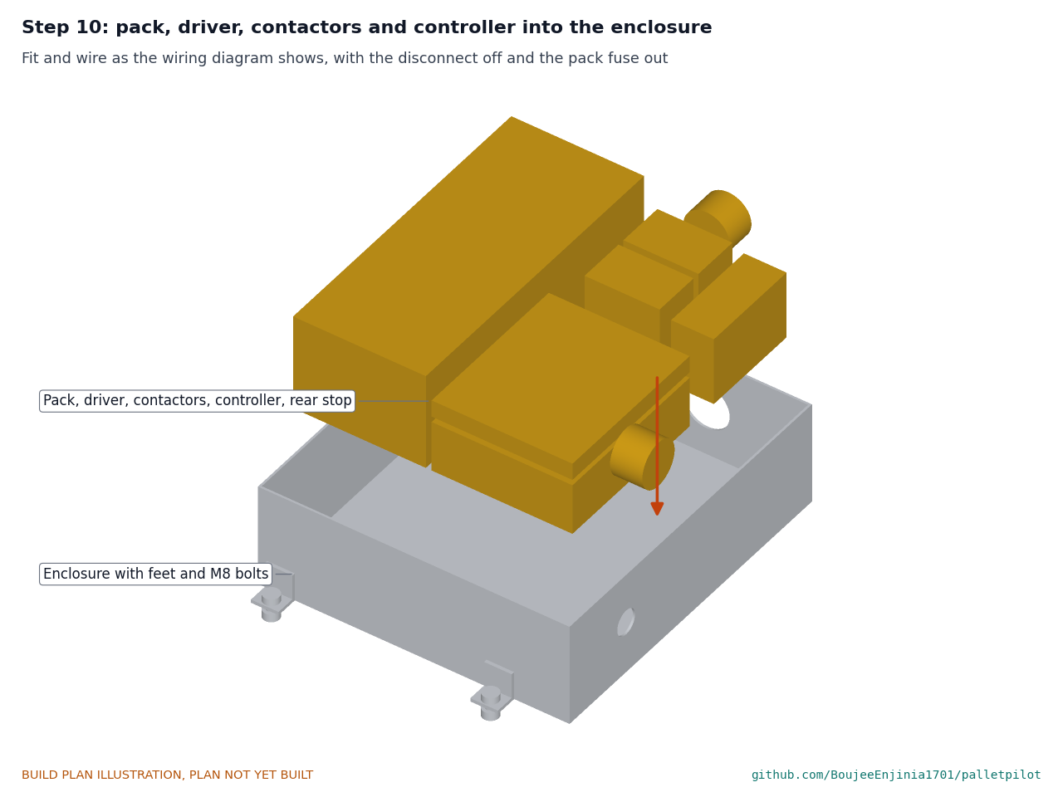
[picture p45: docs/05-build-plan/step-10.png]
Step 10


Fit each module on its own bracket or pads and wire as Figure 19, with the disconnect off and the battery fuse out. Run the motor, safety edge and scanner cables through glands. **Hold point:** the wiring checks of section 3.10.1 pass.

### Step 11: close the lid

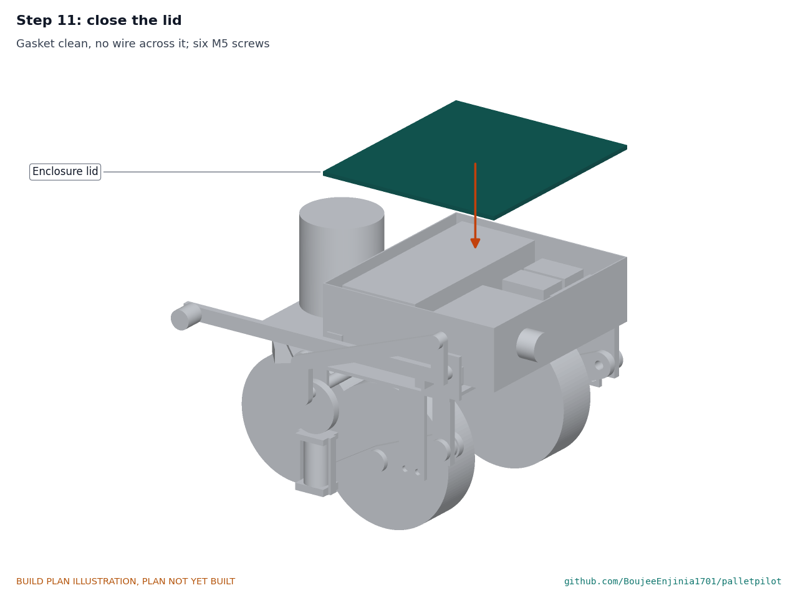
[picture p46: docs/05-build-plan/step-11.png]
Step 11


Check the gasket is clean and no wire lies across it; fit the six M5 screws evenly.

### Step 12: bumper hoop onto the brackets

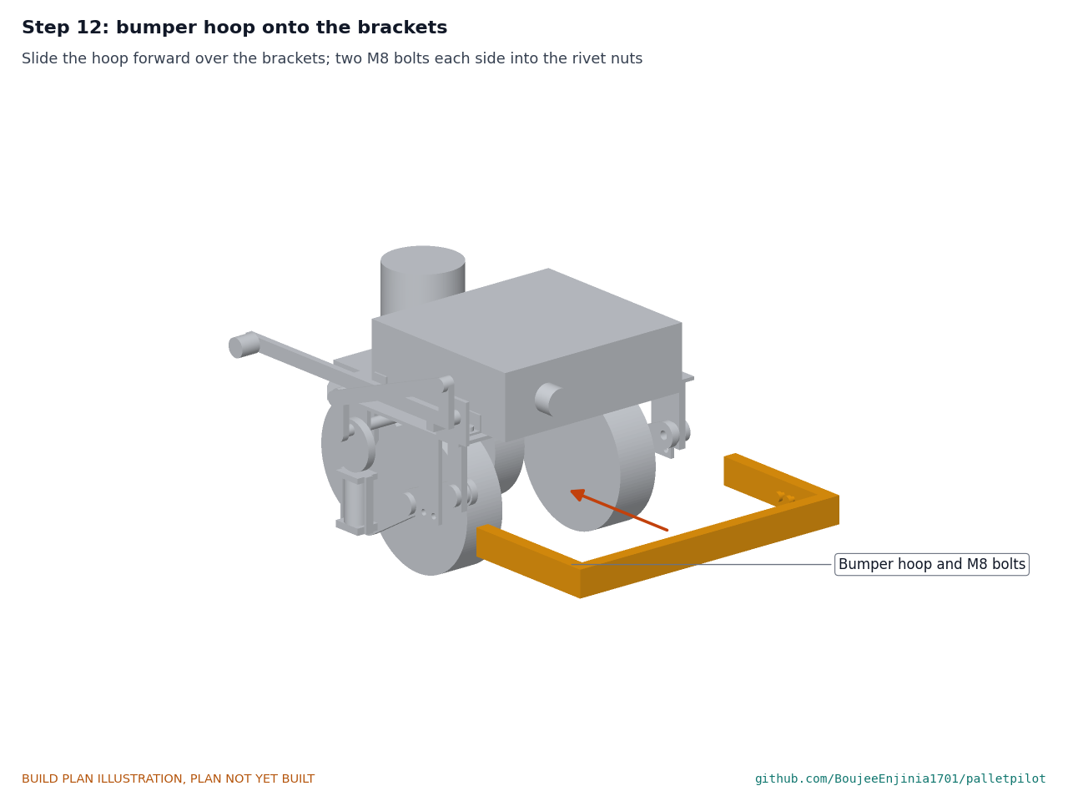
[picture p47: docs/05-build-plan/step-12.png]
Step 12


Slide the hoop forward over the bumper brackets from behind and fit two M8 bolts each side into the rivet nuts.

### Step 13: safety edge onto the hoop

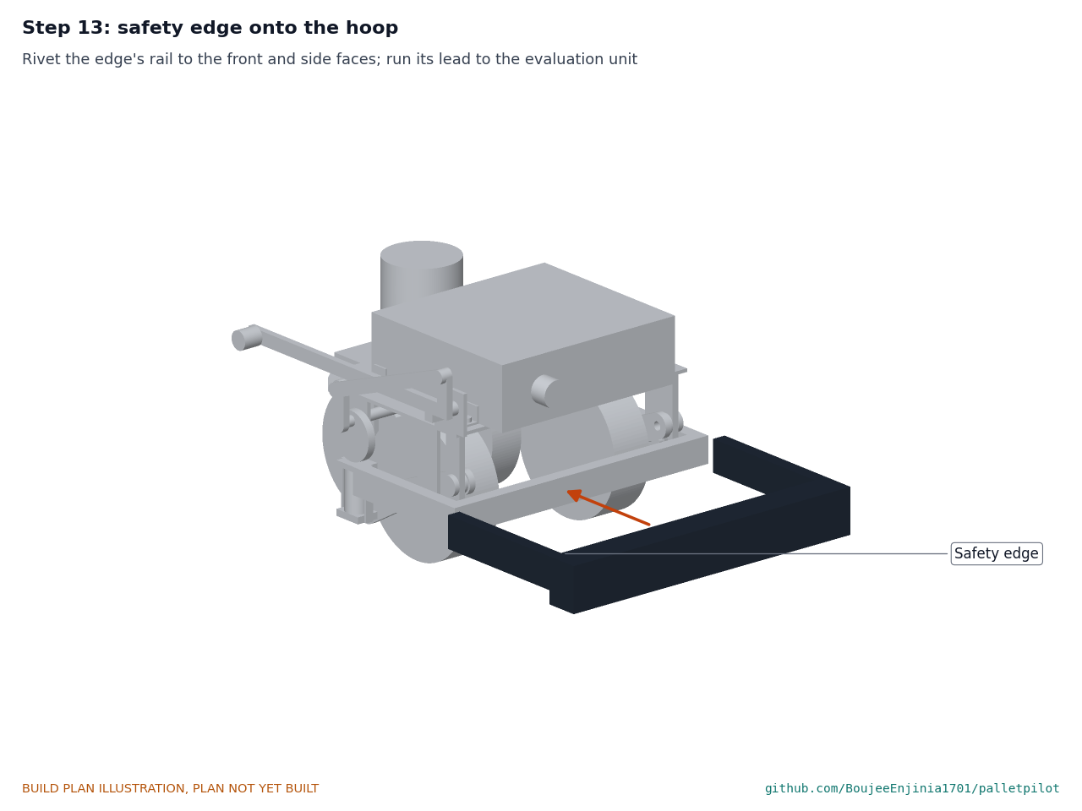
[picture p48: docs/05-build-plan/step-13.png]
Step 13


Rivet the edge's rail to the front and side faces of the hoop and run its lead to the evaluation unit in the enclosure.

### Step 14: safety scanner and corner anchors onto the hoop

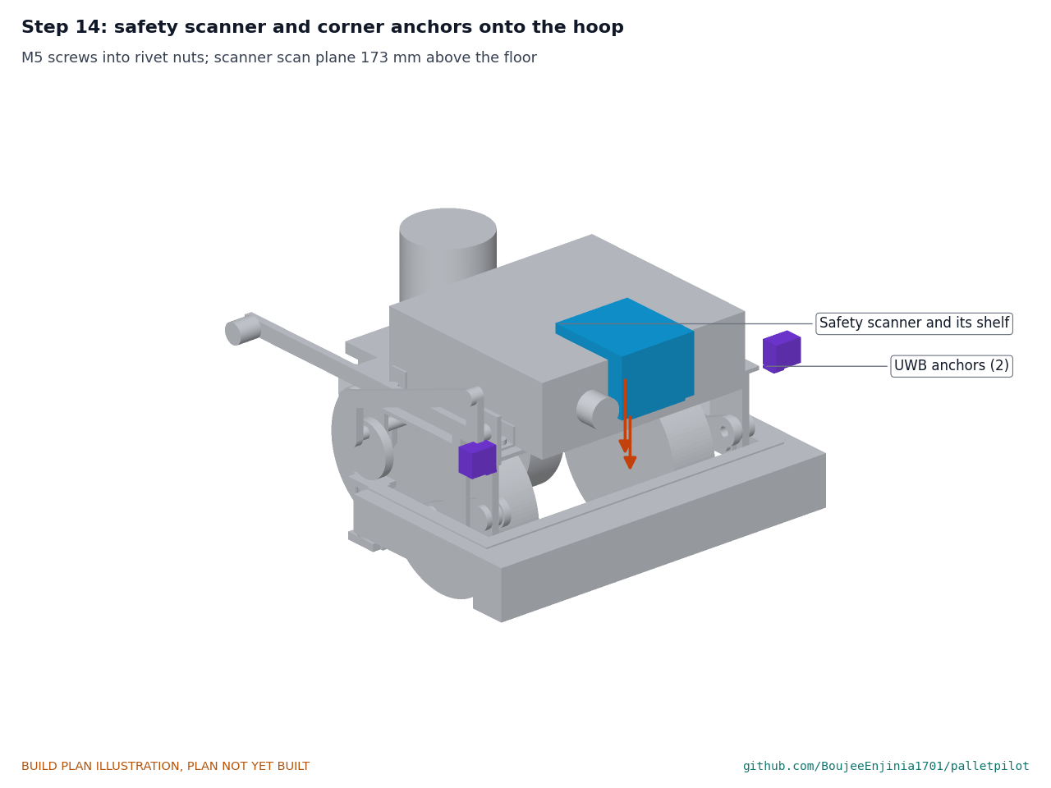
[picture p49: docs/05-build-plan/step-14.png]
Step 14


Screw the scanner shelf and the two anchor plates to the hoop with M5 screws, fit the scanner and anchors, and check the scanner's scan plane is 173 above the floor and the scanner clears the enclosure by at least 5.

### Step 15: tiller head onto the handle

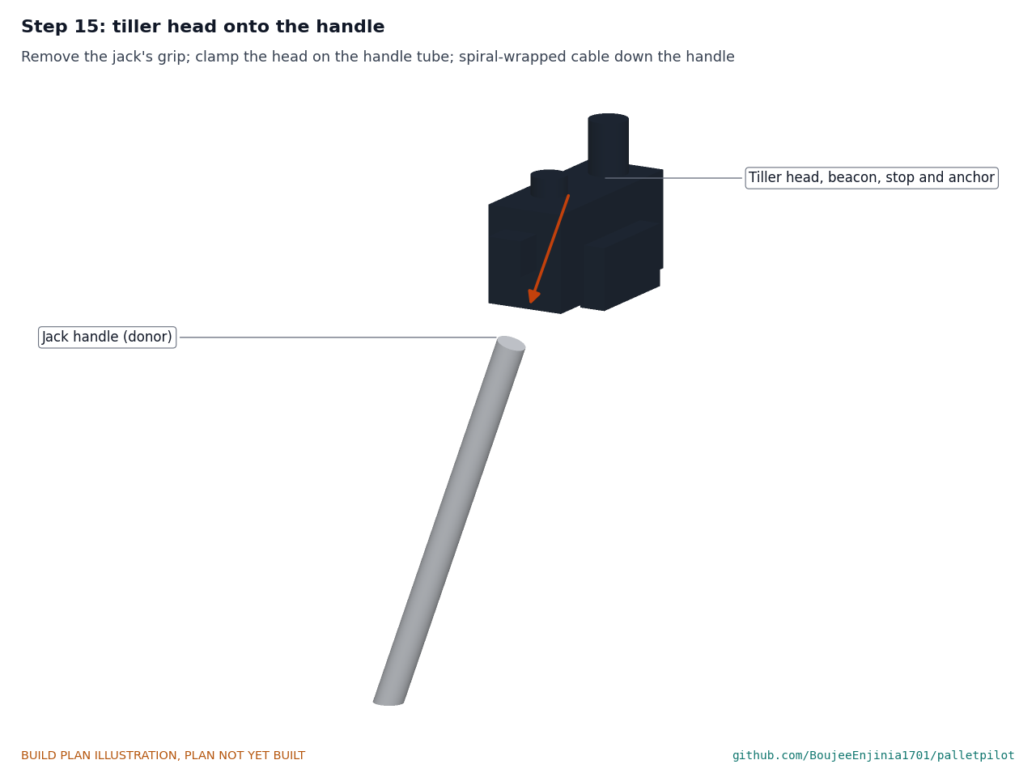
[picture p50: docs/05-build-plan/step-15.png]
Step 15


Remove the jack's grip and clamp the tiller head on the handle tube. Run its cable down the handle in spiral wrap to a gland on the enclosure, leaving slack for the full handle swing and full steering turn. Fit the handle angle sensor at the pivot and the gas spring, as their makers describe. **Hold point:** safety stop S4 in section 6.

## 5. First checks

These are the checks a TRL 4 test report would record; this plan only lists them. Requirement numbers are those of PLP-REQ-001.

*Table 3. First checks.*

| Check | Requirement | How | Pass when |
| --- | --- | --- | --- |
| Clamp and fit | R1 | Time the fitting and removal; look for any drilled or damaged part of the jack | No change to the jack; fitted in 2 h or less, removed in 1 h or less |
| Steering stops | R1, R15 | Turn the handle fully each way, power off | The rubber stops touch the frame first; record the angle (40° expected) |
| Aisle turn | R15 | Walk mode at creep speed with the design load: turn from an aisle into a standard pallet bay; measure the turning radius about the load wheels | The kit makes the right-angle turn into the bay; radius recorded (roughly 1.5 m expected) |
| Handle clearance | R11 | Lower the handle to horizontal over the enclosure | 14 or more of clearance; none of the kit touched |
| Release | R14 | Raise the lever with a spring balance at the grip; time it | Both wheels clear the floor by about 10; effort under 120 N; under 10 s |
| Hand push | R14 | Spring balance on the handle, lever up, jack empty and loaded | Push force within 10 % of the bare jack's |
| Stop chain | R8, R9 | Wheels lifted, power on, wheels turning slowly: press each stop and the edge | Both contactors open and the brakes close within 100 ms (scope on the coils) |
| Brake hold | R10 | Power off, wheels down, on a 2 % slope with the design load | The truck does not move |
| Speed limits | R4 | Wheels lifted; command each mode; measure wheel speed | 1.2, 0.8, 0.3 and 0.15 m/s equivalents, not exceeded |
| Kit mass | R15 | Weigh each subassembly before fitting | About 44 kg in all; recorded against the 40 kg target |
| Added length | R15 | Measure from the steer wheels' back to the bumper face | 290 or less |

## 6. Safety stops

Stop at each point. Carry on only when everything listed is true.

- **S1. Before the battery comes into the workshop.** Pack voltage about 24 to 28 V; no swelling, dents or leaks; the maker's datasheet and BMS limits in hand. A charging spot ready on a non-combustible surface, away from stored goods, with a fire extinguisher for electrical fires within reach.
- **S2. Before the battery fuse goes in.** Wiring checks of section 3.10.1 pass. Polarity checked with a meter at the driver input. Disconnect off. Insulated tools only; no rings or watches.
- **S3. Before the first power-up.** Jack chocked on a level floor, drive wheels lifted with the lever, nobody within reach of the wheels. The safety relay needs its manual reset before anything moves.
- **S4. Before the motors turn.** Both emergency stops and the edge open both contactors (section 5, stop chain). Driver current limits set to the motors' ratings; speed limited to the creep setting.
- **S5. Before the wheels go down on the floor under power.** A cordoned, level, dry area with no other people in it; the operator wears safety footwear; walk mode only, with the handle-angle drive band and belly-reverse paddle checked with the wheels lifted. No load on the forks.
- **S6. Before any load goes on the forks.** All checks of section 5 pass empty. Start with a light pallet and work up; no ramps.
- **S7. Follow mode.** Follow mode is treated as a driverless truck function under ISO 3691-4 (PLP-DEC-001): no trial with people present until its personnel detection and stopping functions meet that standard. Not run until the scanner layer is built and tested, and then only at 0.15 m/s or less in a cordoned area with no other people present, the operator wearing the tag with its stop button.
- **S8. Charging.** Only with the certified charger, on the charging spot, never below 0 °C and never a damaged or swollen pack; never left unattended on a first charge.

## 7. Tools, skills and workspace

**Tools.** Access to a laser or plasma cutting service for the plates and cams; bandsaw or hacksaw; bench drill with drills to 20 mm and a 13 mm drill; M5, M6 and M20 taps and dies; MIG welder; angle grinder with cutting and flap discs; sheet metal folder for 2 mm aluminium (or a sheet metal shop); rivet gun for 4.8 mm rivets and a rivet nut tool for M5 and M8; files, deburring tool, engineer's square, steel rule, calipers, digital angle finder; torque wrench to 100 N·m; spring balance to 200 N; crimp tool for 5.3 mm² lugs and ferrules; wire strippers; multimeter; two-channel oscilloscope or a timing meter for the stop chain; wheel chocks and two axle stands; a scale to 50 kg.

**Skills.** MIG welding of 6 and 10 mm structural steel to a sound standard; marking out and drilling; sheet metal riveting; crimping and wiring of 25.6 V, 80 A circuits; safe handling of lithium iron phosphate packs. The welds on the subframe hangers and the bumper hoop carry the drive and spring loads, so a competent welder should make or check them. No mains wiring is part of the build: the charger is a certified, self-contained unit.

**Workspace.** A fabrication area with fire-safe welding screens, away from the battery and electronics; a clean bench for wiring; a level concrete floor about 3 x 4 m for fitting and first checks, which can be cordoned off; the charging spot of S1. Two people for lifting the motors (about 7 kg each) and fitting the arms.

**Personal protective equipment.** Welding helmet, gloves and flame-resistant clothing for welding; safety glasses and hearing protection for cutting and grinding; safety footwear throughout; no gloves near a turning drill.

## 8. Where the numbers come from

- Model and constructability checks: `cad/src/model.py` (`python cad/src/model.py --check`): overlaps, contacts, the scanner and lever clearances, the release lever's raised state and the steering sweep; STEP and STL exports in `cad/step/` and `cad/stl/`.
- Pictures: `cad/src/build_plan_media.py`, using `.kit/build_views.py`; written to `docs/05-build-plan/` and `cad/drawings/PLP-DWG-101` to `PLP-DWG-111`.
- General arrangement: `cad/drawings/PLP-DWG-001.pdf`, Rev P5.
- Calculations: `docs/04-calcs/01-sizing.md` (PLP-CAL-001 v0.7) and `docs/04-calcs/sizing.py`; mass [B0], [B1], loads [C1] to [C3], torque [F4], stopping [S2], [S3], release [G4], steering [G5].
- Bill of materials: `bom/bom.csv`.
- Decisions: `docs/decisions/0003-design-for-construction.md` (PLP-DDR-003), with PLP-DDR-001 and PLP-DDR-002; open decisions in `docs/06-design-decisions.md` (PLP-DEC-001).
- Requirements: `docs/03-requirements.md` (PLP-REQ-001 v0.7).

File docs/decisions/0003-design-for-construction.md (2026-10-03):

---
doc_id: PLP-DDR-003
title: PalletPilot design for construction
project: PalletPilot
doc_type: Design decision record
version: "0.5"
status: Draft
date: '2026-10-02'
author: Amish Chadha
license: CERN-OHL-S-2.0
revisions:
- version: "0.1"
  date: '2026-10-01'
  author: Amish Chadha
  change: Changes that make the concept physically buildable, with the reason for each; made under Amish's 2026-09-30 instruction to make the design physically buildable; open for his review
- version: "0.2"
  date: '2026-10-01'
  author: Amish Chadha
  change: A1 (steering range) accepted by Amish as recommended, option (a), with the TRL 4 aisle test as a go or no-go gate; Table 1, A2 and A3 stay open
- version: "0.3"
  date: '2026-10-02'
  author: Amish Chadha
  change: "A2 and A3 accepted by Amish on 2026-10-02 (R15 prototype limit 45 kg; 10 mm lift for smooth indoor floors only); Table 1 changes still open"
- version: "0.4"
  date: '2026-10-02'
  author: Amish Chadha
  change: "Table 1 changes (P1 to P10) accepted by Amish on 2026-10-02"
- version: "0.5"
  date: '2026-10-02'
  author: Amish Chadha
  change: "Approved follow-ups carried into the model: 5 mm top plate, tube lever and two hollow pivots (A2); safety laser scanner in place of the lidar (ISO 3691-4); Table 4 added; Consequences updated"
---

# 0003: Design for construction

- **Date:** 2026-10-01
- **Status:** accepted. Amish, 2026-10-02: "APPROVED: Design-for-construction changes in 10 repos (CityTwin, CoolShade, PalletPilot, Heliolite, PotholeLog, EarthPress, ReadyKit, CellCheck, CargoMule and ThermaCart)". This covers the changes P1 to P10 in Table 1, made under Amish's 2026-09-30 instruction to make the design physically buildable, and is recorded in the design decisions register (PLP-DEC-001). The items in Table 3 change what the kit does or how it is pitched, so they were proposed separately and listed in the register. A1 is decided: Amish, 2026-10-01: "i accept your recommendations for PalletPilot". He was given the recommendation for A1 only, so A1 is decided as recommended (option a, with the TRL 4 aisle test as a go or no-go gate) and recorded in PLP-DEC-001. A2 and A3 are decided: Amish, 2026-10-02: "i approve your recommendations for all 555 open decisions." A2 is decided as option (a) with R15's prototype limit restated as 45 kg, and A3 as option (a) for smooth indoor floors only; both are recorded in PLP-DEC-001.

## Context

On 2026-09-30 Amish asked for every repo to have an illustrated build plan and wrote: "If you are realising that the design cannot be built as per concept - fix the design assumptions to match and be physically feasible as you draw the illustrations." The TRL 3 model of PalletPilot showed what the kit does, but it was a massing model: several parts had no fixing, floated in space, overlapped other parts, or could not do the job the concept gives them. Checking the model with build123d found the problems in Table 1.

The changes keep what the kit does: the same drive layout (two 200 mm hub motors on a 260 mm track, 180 mm behind the steering axis, 1.5 kN spring preload), the same enclosure under the handle sweep, the same bumper face, lidar scan plane and anchor baseline, the same electrical parts and the same stop chain. The added length (290 mm), handle clearance (40 mm at 70°, 14 mm lowered flat), stopping, traction, energy and tracking figures are unchanged. Every change is in `cad/src/model.py`, which now runs constructability checks (`python cad/src/model.py --check`): 46 pairs of parts that must touch do touch, no two of the 36 components share volume, nothing collides with the release lever raised, and the steering sweep is checked against the jack's frame. All pass.

## Decision

*Table 1. Changes made to the model, the BOM and the calculations.*

| # | Problem in the concept | Change made | Why this way |
| --- | --- | --- | --- |
| P1 | The subframe was a 20 mm slab with a clamp block 10 mm short of the yoke and a tongue under it, held by nothing. It could not grip the yoke. | A 6 mm top plate rests on the yoke plate's rear margin with a 62 mm radius notch round the pump. A 10 mm lower jaw goes under the margin, with a packing bar behind the yoke's edge, and four M12 bolts behind the edge pull the jaw and the top plate together, gripping the yoke plate between them. | R1 forbids drilling the jack. The bolts pass behind the yoke's edge, not through it; the pump in the notch stops the plate sliding back, and the packing bar stops it sliding forward. |
| P2 | The trailing cheeks were welded solid to the plate, so the wheels could not move, and the two spring towers floated outside the plate touching nothing. The 1.5 kN preload had nothing to act on. | Each hub motor is carried by its own drive arm (10 mm plate) that pivots on a 20 mm pin in two rear hangers behind the wheels. The arm's front end carries a spring tab; a 100 N/mm spring between the tab and a saddle under a cam pushes the arm, and so the wheel, down. The arm ratio of 1.77 gives 750 N per wheel from 423 N per spring. | A pivoted arm is the simplest sprung mount. The pivot behind the wheel leaves the space ahead of the wheel for the spring and the release, and keeps every part between the steer wheels and the bumper. The stiff spring lets the empty jack's steer wheels lift only about 1.2 mm, as PLP-CAL-001 [C3] asks. |
| P3 | The hub motors sat 5 mm from the cheeks with no shaft between them. | Each motor's fixed shaft passes through the arm's axle hole with a 5 mm spacer inside and a nut outside. | This is how a single-sided hub servo motor is mounted; the shaft size is confirmed when a motor is chosen. |
| P4 | The release lever was a bar along the enclosure side with no pivot and no link to the springs, so it could not lift anything. | A 16 mm cam shaft runs across under the top plate in two front hangers, with a 22 mm eccentric cam above each spring saddle and a crank on its left end. A link joins the crank to an up-arm on a 400 mm lever pivoted on a bracket on the top plate, making a parallelogram. Raising the lever a quarter turn lifts the saddles 22 mm; slotted straps then lift the arms, and the drive wheels clear the floor by 10 mm. With the wheels down the lever lies forward on a stop, over centre. | One lever lifts both wheels (R14) with a peak effort of about 58 N, half the 117 N the concept estimated [G4]. Every moving part was checked in both lever positions. |
| P5 | The bumper was a single solid block, and its mounts ran from the cheeks (which now move with the wheels) to the hoop's sides, which reached forward to 70 mm behind the steering axis. | A U hoop of 40 x 20 x 2 mm tube, its side legs bolted with two M8 bolts each into rivet nuts on brackets welded under the top plate. The safety edge is riveted to the front (50 mm deep, 40 mm travel) and to both sides (20 mm). The side legs start 120 mm behind the steering axis. | The hoop is fixed to the parts that do not spring, so the bumper face stays put. The bumper face, width (480 mm) and edge travel are unchanged, so R8 stands. Edge length is now about 0.9 m, not 1.3 m. |
| P6 | The lidar bracket hung from the subframe in the space the arm pivot now needs. | A bent steel strap screwed to the top of the hoop's front bar carries the lidar shelf. | Scan plane (200 mm) and the lidar's position 10 mm behind the bumper face are unchanged. |
| P7 | The two bumper anchors floated above the bumper with no fixing. | Each anchor sits on a small corner plate on top of the hoop's front corners, its top 180 mm above the floor, below the scan plane. | Baseline (450 mm) unchanged, so the tracking budget [U1] to [U4] stands. |
| P8 | The enclosure had no fixing; the rear emergency stop and the disconnect overlapped its walls. | Four aluminium angle feet riveted to the box sides, each bolted through the top plate with an M8 bolt; holes in the walls for the stop (22 mm) and the disconnect (40 mm). | The box floor stays whole, so nothing inside sits on a bolt head. The box is 89 mm deep plus a 6 mm lid, 95 mm as before. |
| P9 | With the kit on, the yoke cannot turn as far as a bare jack: the drive end reaches the jack's frame head. On the reference donor the top plate's corners met it at 34° and the cams, link and wheels at 44° to 48°. | The top plate's front corners are cut off at 45° (50 mm), and two rubber steering stops under them meet the frame head flat at 40° each way, 4° before any other kit part. | Without stops, steel parts of the kit would strike the jack's frame. The stop angle is set by the donor survey (R1). The range itself is a change to what the kit does: see Table 3, A1. |
| P10 | The donor reference geometry overlapped itself: the steer wheels ran through the yoke plate and the frame head, and the pump through the yoke. | Reference donor corrected: yoke plate 204 to 219 mm above the floor over 180 mm steer wheels, frame head's rear face 100 mm ahead of the steering axis, yoke side legs added. | Reference geometry only; still a survey item (R1, O3). |

*Table 2. Knock-on changes.*

| Item | Change | Reason |
| --- | --- | --- |
| Mass | Kit 44.4 kg (was 42.0 kg) [B1]: drive module 10.6 kg (was 9.8), release mechanism 3.3 kg (was 0.8), bumper 2.3 kg (was 3.3), steering stops 0.1 kg. R15 mass is now 4.4 kg over its 40 kg target (2.0 kg was accepted for now in PLP-DDR-002). | Made parts are now weighed from their modelled volumes. |
| Cost | BOM lines 1 ($90 to $130), 3 ($45 to $50) and 13 ($20 to $45) repriced and line 19 (steering stops, $10) added: $1,690. Value-engineering target: USD 1,610 (`budget_usd`, unchanged). Estimated cost of the constructable design: USD 1,690 (USD 80 over the target) [K1]. | Parts added for construction. |
| Calculations | PLP-CAL-001 v0.4: mass, loads and forces rerun (design total 1,108 kg; worst motor torque 25.6 N·m of 30; ramp margin 1.53; bumper-only stop 39 mm of 40 mm; 28 % of usable energy left); lever effort [G4] 58 N; steering range [G5]. No requirement changed status. | Follows the model. |
| Drawings | PLP-DWG-001 Rev P4; making sketches PLP-DWG-101 to 111 added; concept blueprint PLP-DWG-010 Rev P2. | Follows the model. |
| Documents | PLP-REQ-001 v0.6 and PLP-PRC-001 v0.6: mass, cost, release and steering figures. | Follows the model. |

*Table 3. Proposed; A1 accepted by Amish as recommended on 2026-10-01, A2 and A3 on 2026-10-02.*

| # | Question | Options | Recommendation |
| --- | --- | --- | --- |
| A1 | Steering range. With the kit fitted the jack steers about 40° each way, against about 90° bare, on the reference donor. The concept says the kit "steers with the handle like the bare jack"; it does not. A wider turn needs more room in aisles. | (a) Accept for the prototype, set the stops from the donor survey and measure the turning circle at TRL 4; (b) narrow the drive end (hoop sides inboard, release moved) for perhaps 48°, at the cost of a narrower anchor baseline and a worse R5; (c) a different drive layout, for example one centre drive wheel under the yoke, which reopens D3. | (a), and state the steering range in the precis and README; make the TRL 4 aisle test a go or no-go gate: if the kit cannot make a right-angle turn into a standard pallet bay, change the drive layout (option c) before TRL 5. **Accepted by Amish, 2026-10-01.** |
| A2 | Mass. The kit is 44.4 kg against R15's 40 kg; Amish accepted 2.0 kg over for now. | (a) Accept for the prototype and recheck at the motor quote; (b) lighten now: 5 mm top plate, tube lever, hollow pivot pin (about 1.5 kg). | (a), keeping (b) as savings to try in the TRL 4 drawings. **Accepted by Amish, 2026-10-02**, with R15's prototype limit restated as 45 kg and rechecked at the motor quote. |
| A3 | Wheel lift. The lever lifts the drive wheels 10 mm clear. A larger lift needs a larger cam, which the top plate's height does not leave room for. | (a) Accept 10 mm for smooth indoor floors; (b) lower the cam shaft and raise the hangers for about 15 mm. | (a). **Accepted by Amish, 2026-10-02**, for smooth indoor floors only; the build plan says so. |

*Table 4. Follow-ups of the 2026-10-02 decisions, carried into the model.*

| # | Change | Why |
| --- | --- | --- |
| F1 | The top plate is 5 mm (was 6 mm), the release lever is a 20 x 10 x 2 mm steel tube (was a solid bar), and the single 20 mm pivot pin is replaced by two hollow 20 mm tubes with a 4 mm wall, one per drive arm, each held by an M12 bolt through its bore. The enclosure sits 1 mm lower on the thinner plate and is 96 mm deep. | A2 (approved 2026-10-02): about 2.0 kg saved. Two short pivots also leave the middle of the frame free for the scanner. |
| F2 | The lidar is replaced by a safety laser scanner (SICK nanoScan3 class, about 107 x 80 x 118 mm) on a 3 mm steel shelf on the hoop's front bar, scan plane 173 mm above the floor (was 200 mm). The safety edge is 68 mm high (was 80 mm) and the anchor tops are 165 mm (was 180 mm) so that both stay clear of the shelf and the scan plane. | Follow mode is treated under ISO 3691-4 (approved 2026-10-02), which needs a safety-rated personnel sensor. The body is larger than the lidar's, and it must fit between the bumper and the enclosure with 5 mm to spare. |
| F3 | Personnel stop: scanner to the safety relay, monitored controlled stop (stop category 1) by the driver, brakes close at standstill; the relay opens both contactors if the monitored time runs out. Field 0.80 m (was 0.86 m); the delay is 0.15 s (was 0.25 s). | PLP-CAL-001 v0.7 [S4], [S5], [S5a]. |

The constructability checks now include clearances for the scanner and lever (nine gaps). The steering stops, the donor survey items (packing bar thickness, clamp holes, notch, stop angle) and everything else in Tables 1 to 3 are unchanged; the survey items wait for the three surveyed jacks.

## Consequences

- `design_state: constructable` in `project.yaml`. The build plan PLP-BLD-001 shows every component and step in pictures generated from the model (`cad/src/build_plan_media.py`); open decisions are in PLP-DEC-001.
- Requirement status is unchanged by the changes: 10 met, 2 not met (R5, R15 mass), 2 at risk (R7, R9), 3 not verifiable at TRL 3 (R1, R6, R16). With A2 decided on 2026-10-02 (R15 prototype limit 45 kg) it is 11 met and 1 not met (R5); with the follow-ups of Table 4 the kit is 42.9 kg and R17 is reported against the value-engineering target, USD 3,455 over (USD 5,065 against USD 1,610; USD 80 over before the safety scanner).
- The appearance model `cad/src/product_model.py` now takes its drive module, release, hoop, scanner shelf and steering stops from the constructable model (2026-10-02), and the render scenes are exported. The photoreal renders (`media/render-*.png`), `media/card.png` and `media/social-preview.png` still show the earlier design until they are remade on Amish's Mac, where Blender is.
- With A1 accepted (2026-10-01), the prototype steers about 40° each way with the kit fitted, set by rubber stops (a bare jack turns about 90°), for a turning radius of roughly 1.5 m about the load wheels; the range is confirmed in the TRL 4 aisle test. The precis (PLP-PRC-001 v0.7), README, requirements (PLP-REQ-001 v0.7) and build plan (PLP-BLD-001 v0.2) state this range. The TRL 4 aisle test is a go or no-go gate: if the kit cannot make a right-angle turn into a standard pallet bay, the drive layout changes before TRL 5 (option c, for example one centre drive wheel under the yoke, which reopens D3 of PLP-DDR-001).
- The donor survey (R1, O3) now sets four numbers in the build: the yoke plate's thickness (packing bar), its rear edge and the pump's position (notch and clamp), and the frame head's position (steering stop angle).

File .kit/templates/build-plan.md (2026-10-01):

---
doc_id: PRJ-BLD-001
title: Project prototype build plan
project: Project name
doc_type: Build plan
version: "0.1"
status: Draft
date: YYYY-MM-DD
author: Amish Chadha
license: CERN-OHL-S-2.0
revisions:
  - version: "0.1"
    date: YYYY-MM-DD
    author: Amish Chadha
    change: First build plan; design made constructable
---

# Project prototype build plan

**Plan, not yet built.** How to build the first proof-of-concept prototype, component by component. Building and testing to it is TRL 4 work. Decisions still to be made are kept in the design decisions register (`docs/06-design-decisions.md`), not here.

## 1. What you are building

Every component, pulled apart and numbered in build order

One short paragraph: what the prototype is, how many components, which are made and which are bought, and the main ways they are made.

## 2. What changed to make it buildable

| Component | The concept had | The buildable design has | Why |
| --- | --- | --- | --- |

## 3. Making the components

### 3.1 Component name

Making sketch

**What it is and what it is made from.**

**How to make it.**

1. Mark out ...
2. Cut ...

**How it fits the parts next to it.**

Close-up of the joint

**Check before moving on.**

## 4. Putting it together

### Step 1: ...

Step 1

## 5. First checks

| Check | Requirement | How | Pass when |
| --- | --- | --- | --- |

## 6. Safety stops

## 7. Tools, skills and workspace

## 8. Where the numbers come from

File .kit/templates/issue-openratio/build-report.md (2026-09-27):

---
name: Build report
about: Tell us what happened when you built, printed or tested part of this design
title: "Build report: "
labels: build-report
---

This is a research and educational prototype, not a medical device. It is a TRL 3 concept and is not released for fabrication. If you build any part of it, you do so at your own risk. Reports help everyone.

**What you built** (part, sub-assembly or test)

**Materials, tools and settings**

**What worked**

**What did not work, with photos or measurements if you have them**

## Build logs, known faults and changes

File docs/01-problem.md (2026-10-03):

---
doc_id: PLP-PRB-001
title: PalletPilot problem statement
project: PalletPilot
doc_type: Problem statement
version: "0.6"
status: Draft
date: '2026-10-02'
author: Amish Chadha
license: CERN-OHL-S-2.0
revisions:
- version: "0.1"
  date: '2026-09-24'
  author: Amish Chadha
  change: Initial scaffold
- version: "0.2"
  date: '2026-09-25'
  author: Amish Chadha
  change: Populate to TRL 2 (problem, users, context, constraints, out of scope, prior work with sources)
- version: "0.3"
  date: '2026-09-25'
  author: Amish Chadha
  change: Record decisions PLP-DDR-001 (budget $1,550, layered stopping, research-use legal route, partner types); OSHA wording checked against the source
- version: "0.4"
  date: '2026-09-26'
  author: Amish Chadha
  change: Budget approved by Amish ($1,610, PLP-DDR-002)
- version: "0.5"
  date: '2026-10-02'
  author: Amish Chadha
  change: "Follow mode classification, donor survey and first candidate partners decided by Amish on 2026-10-02 (PLP-DEC-001)"
- version: "0.6"
  date: '2026-10-02'
  author: Amish Chadha
  change: "Approved follow-up: the stop layer in follow mode is a safety laser scanner (ISO 3691-4), not a lidar"
---

# PalletPilot problem statement

Small warehouses, shops and workshops move pallets with manual pallet jacks, and a loaded jack takes more force to start and keep rolling than ergonomic limits allow for repeated shifts. Powered walkie pallet jacks now cost from about $1,640, but trucks that follow the operator hands-free are forklift-class products well beyond a small business. PalletPilot is an open retrofit kit that adds powered drive, a follow-me mode and layered stopping to the manual jack the site already owns.

## The problem

A manual pallet jack is the most common load mover in small facilities. A typical unit has 685 x 1220 mm (27 x 48 in) forks, a 2,500 kg (5,500 lb) rating, a 75 mm (3 in) lowered height and a mass of about 64 kg (140 lb), and costs about $396 new ([Global Industrial](https://www.globalindustrial.com/p/global-industrial-153-standard-duty-pallet-jack-truck-5500-lb-capacity-27-x-48-forks)).

Moving it loaded is hard work:

- **Force.** With a 1,000 kg pallet, the rolling force is about 130 N (13 kgf) and the force to start moving is about 270 N (28 kgf), assuming 1.2 % rolling resistance and 2.5 % breakaway resistance for polyurethane wheels on smooth concrete (estimates; to be measured). The widely used Liberty Mutual tables give maximum acceptable initial push forces of about 9 to 22 kg for 90 % of female workers, and sustained forces of about 4 to 14 kg, depending on handle height, distance and frequency ([Ciriello and Snook 1991, summarized by MHI](https://og.mhi.org/media/members/14023/130258038292642021.pdf)). A heavy pallet on a manual jack is at or past those limits every time it starts.
- **Walking time.** Order picking and staging are mostly walking. The operator pulls the jack, stops, walks back to pick, and pulls again. A truck that follows the operator removes the repeated grab, pull and release.

Three kinds of product exist, and none fits a small site well:

1. **Powered walkie pallet jacks.** A basic lithium walkie with 1,500 kg (3,300 lb) capacity now sells for about $1,640 ([Home Depot, Tory Carrier A-1034](https://www.homedepot.com/p/3300-lbs-24V-20AH-Lithium-Battery-Electric-Pallet-Jack-Walkie-Truck-w-48-in-x-27-in-Fork-Size-3-1-in-Fork-Lowered-A-1034/326396102)). This solves the force problem but not the walking problem, and the site's existing manual jacks sit idle.
2. **Bolt-on power kits.** The PowerHandling PowerPallet 2000 converts a manual jack to powered drive in 10 to 20 minutes, with a 1,590 kg (3,500 lb) rating and a top speed of 1.65 m/s (3.7 mph), for about $2,084 to $2,294 ([HoF Equipment](https://hofequipment.com/PowerHandling-Power-Pallet-2000-p1957.html); [F.E. Bennett](https://febennett.com/product/powerhandling-power-drive-retrofit-kit-for-pallet-jacks/)). It proves the retrofit idea works but costs more than a new walkie and has no follow mode.
3. **Follow-me trucks.** Jungheinrich's easyPILOT Follow, shown at LogiMAT 2018, lets a low-level order picker follow an operator who carries a UWB control unit, with laser scanners for obstacle detection ([Jungheinrich](https://www.jungheinrich.com/en/press-events/press-releases/easypilot-follow-faster-order-picking-with-the-new-semi-automatic-control-unit-158956)). It is an option on a full order-picking truck, not something a small business can add to a manual jack.

So a retrofit kit only earns its place if it does something a cheap walkie does not: follow-me operation, reuse of existing jacks and open, repairable parts. The kit's cost has to stay well below a new walkie plus a follow-me system.

## Users and context

| User | Need | Context |
| --- | --- | --- |
| Small warehouse or 3PL operator | Move 20 to 100 pallets a shift without a forklift or a second worker | Single shift, one to five staff, concrete floor, some ramps |
| Retail backroom and grocery receiving | Stage deliveries and restock aisles, often one person working alone | Tight aisles, customers nearby, early-morning deliveries |
| Workshop, maker space or small manufacturer | Move raw stock and finished goods between machines | Mixed traffic, cables and debris on the floor |
| Order picker | Pick cartons onto a pallet while walking an aisle, without pulling the jack at every stop | Stop-start, short moves of 2 to 10 m |
| Maintenance person | Fit, inspect and repair the kit with ordinary tools and parts | No dealer service contract |

### Operating environment

- **Floors:** sealed or bare concrete, level, with expansion joints, dock plates and short ramps up to about 2 % grade. Dust, stretch-wrap scraps and small debris are common.
- **Loads:** pallets of 200 to 1,500 kg on 1,200 x 1,000 mm (48 x 40 in) stringer or block pallets.
- **Traffic:** people on foot, other jacks, occasionally a forklift; customers in retail backrooms.
- **Climate:** indoor, 0 to 40 °C; unheated storage and loading bays in winter.
- **Power:** ordinary 120 V or 230 V outlets for overnight charging.

## Constraints

- Garage-buildable prototype, $1,610 USD for the kit (budget raised from $1,200 to $1,550 by Amish on 2026-09-25, PLP-DDR-001, and to $1,610 on 2026-09-26 to cover the priced BOM, PLP-DDR-002). The donor manual jack is not included.
- Bolt-on to a common 27 x 48 in manual jack with no welding, cutting or drilling of the jack's load-bearing structure, and removable to restore the jack.
- Keep the jack's 75 mm lowered height, fork length and its ability to enter a standard pallet.
- Walking pace only, with layered stopping as the pitch states: hardwired emergency stops, a non-contact safety laser scanner stop layer in follow mode, and a stop on bumper contact as the last layer.
- Low-voltage (24 V class) DC system with a lithium iron phosphate pack.
- Legal and workplace rules: in the United States a motorized pallet jack is a powered industrial truck, so every operator needs formal training and evaluation under 29 CFR 1910.178(l) ([OSHA 1910.178](https://www.osha.gov/laws-regs/regulations/standardnumber/1910/1910.178); [summary](https://www.safetyvideos.com/OSHA-Regulations-for-Pallet-Jack-Use)). The same standard states that "modifications and additions which affect capacity and safe operation shall not be performed by the customer or user without manufacturers prior written approval" (1910.178(a)(4), wording checked against the OSHA page on 2026-09-25). A retrofit on a jack in a workplace therefore needs the jack maker's approval. Amish decided on 2026-09-25 to document the kit for research use now and to approach a jack maker before any workplace trial (PLP-DDR-001, D8).
- A truck that moves with no one at the tiller comes close to the scope of ISO 3691-4 for driverless industrial trucks, which calls for personnel detection that stops the truck before it contacts a person ([ISO 3691-4](https://www.iso.org/standard/70660.html); [overview](https://www.fabrico.io/blog/iso-3691-4-driverless-industrial-trucks/)). How a follow-me mode is classified must be settled before any trial with people. Decided 2026-10-02 (PLP-DEC-001): follow mode is treated as a driverless truck function under ISO 3691-4, with personnel detection and stopping functions to that standard, unless a standards body or a notified body confirms that the walking follower counts as the operator.

## Out of scope

- Powered lifting. The donor jack's hand pump stays.
- Autonomous navigation, mapping or fleet management.
- Ride-on platforms or speeds above walking pace.
- Outdoor use, rough ground and steep ramps.
- Use in hazardous (explosive) atmospheres, cold stores below 0 °C and food-grade washdown areas.
- A commercial product. The first builds are research and demonstration prototypes.

## Prior work

- **Manual pallet jacks.** Commodity 2,500 kg jacks at about $396 set the donor platform and its dimensions ([Global Industrial](https://www.globalindustrial.com/p/global-industrial-153-standard-duty-pallet-jack-truck-5500-lb-capacity-27-x-48-forks)).
- **Low-cost lithium walkies.** About $1,640 for a 1,500 kg, 24 V, 20 Ah walkie ([Home Depot](https://www.homedepot.com/p/3300-lbs-24V-20AH-Lithium-Battery-Electric-Pallet-Jack-Walkie-Truck-w-48-in-x-27-in-Fork-Size-3-1-in-Fork-Lowered-A-1034/326396102)). This is the price ceiling that a retrofit kit has to beat.
- **Retrofit power kits.** The PowerPallet 2000 shows a clamp-on drive unit with a quick-change lithium pack and a truck mode at 0.67 m/s (1.5 mph) ([HoF Equipment](https://hofequipment.com/PowerHandling-Power-Pallet-2000-p1957.html)).
- **Follow-me order pickers.** easyPILOT Follow pairs UWB operator tracking with laser scanners ([Jungheinrich](https://www.jungheinrich.com/en/press-events/press-releases/easypilot-follow-faster-order-picking-with-the-new-semi-automatic-control-unit-158956)). The laser scanners matter: UWB tells the truck where the operator is, not where anyone else is.
- **UWB ranging modules.** Qorvo's DWM3000 module ranges to about 10 cm precision on UWB channels 5 and 9 ([Qorvo](https://www.qorvo.com/products/p/DWM3000)), which makes a low-cost operator tag practical.
- **Ergonomic push limits.** Ciriello and Snook's tables set the target for how much the kit must take off the operator ([MHI summary](https://og.mhi.org/media/members/14023/130258038292642021.pdf)).

## Open questions

- Legal route for a workplace retrofit under 1910.178(a)(4): decided 2026-09-25 (PLP-DDR-001, D8): research use now, a jack maker's written approval before any workplace trial. Which jack maker to approach is open.
- Classification of follow-me mode (ISO 3691-4 or not) and the safety functions it then needs. Decided 2026-10-02: a driverless truck function under ISO 3691-4 (PLP-DEC-001).
- Which donor jack models and steering yokes to support first. Decided 2026-10-02: a survey of three widely sold 27 x 48 in, 2,500 kg jacks with published dimensioned drawings, a Crown PTH 50 series class model, a distributor's standard model such as Uline's and the Harbor Freight Pittsburgh 5,500 lb jack (PLP-DEC-001).
- Are small sites willing to wear a UWB tag and to train every operator as a powered truck operator?
- Typical pallet mass and move distance per shift at real sites, to replace the assumed 60 moves of 40 m.

## User research and co-design

This design is for workplaces the author does not work in, so requirements come from the people who will use it.

- [ ] Identify partners: one small warehouse and one maker space, as decided on 2026-09-25 (PLP-DDR-001, D9). Decided 2026-10-02: the first candidates to approach are Dallas Makerspace and a small food bank or charity warehouse in the Dallas and Fort Worth area, which trials only after the jack maker's written approval under D8; nothing is agreed (PLP-DEC-001)
- [ ] Observe a full shift: pallet masses, distances, floor condition, ramps, traffic and how often the operator walks back to the jack
- [ ] Talk to a safety professional and a jack maker about training and modification approval
- [ ] Revise requirements (REQ) from findings before freezing the design

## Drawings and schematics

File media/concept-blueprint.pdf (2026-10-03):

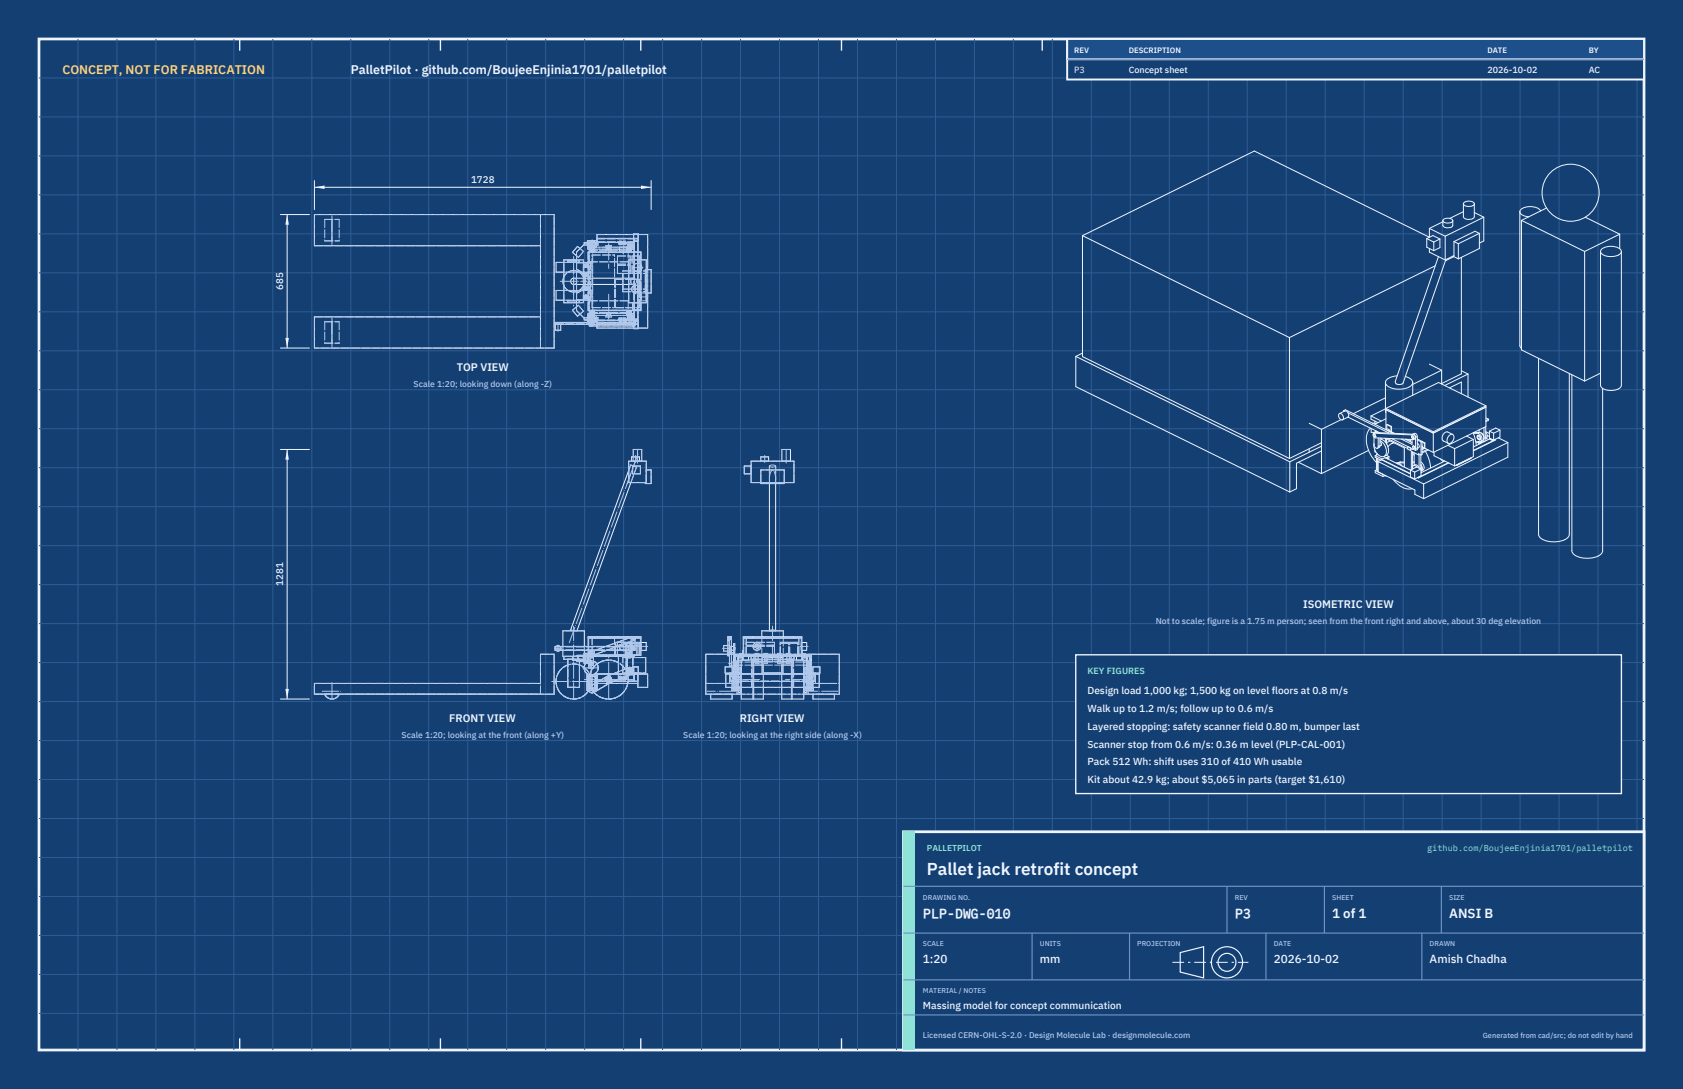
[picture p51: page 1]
CONCEPT, NOT FOR FABRICATION; PalletPilot · github.com/BoujeeEnjinia1701/palletpilot; FRONT VIEW; TOP VIEW; RIGHT VIEW; ISOMETRIC VIEW; REV; DESCRIPTION; DATE; Concept sheet; PALLETPILOT; github.com/BoujeeEnjinia1701/palletpilot; DRAWING NO. PLP-DWG-010; REV P3; SHEET 1 of 1; SIZE ANSI B; SCALE 1:20; UNITS mm; PROJECTION; DRAWN Amish Chadha; Licensed CERN-OHL-S-2.0 · Design Molecule Lab · designmolecule.com; Generated from cad/src; do not edit by hand

Scale 1:20; looking down (along -Z)

Not to scale; figure is a 1.75 m person; seen from the front right and above, about 30 deg elevation

KEY FIGURES
Design load 1,000 kg; 1,500 kg on level floors at 0.8 m/s
Walk up to 1.2 m/s; follow up to 0.6 m/s
Layered stopping: safety scanner field 0.80 m, bumper last
Scanner stop from 0.6 m/s: 0.36 m level (PLP-CAL-001)
Pack 512 Wh: shift uses 310 of 410 Wh usable
Kit about 42.9 kg; about $5,065 in parts (target $1,610)

Scale 1:20; looking at the front (along +Y)

Scale 1:20; looking at the right side (along -X)

Pallet jack retrofit concept

MATERIAL / NOTES
Massing model for concept communication

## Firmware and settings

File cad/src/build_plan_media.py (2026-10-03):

"""PalletPilot prototype build plan pictures (PLP-BLD-001, STANDARDS section 18).

Run from the repo root:  python cad/src/build_plan_media.py [overview|sheets|joints|steps|wiring ...]
With no argument it draws everything. Every picture is drawn from cad/src/model.py
(build_components), so the pictures and the model never disagree:
    docs/05-build-plan/overview.png        every component pulled apart, numbered in build order
    cad/drawings/PLP-DWG-101 to 111        making sketches for the made components
    docs/05-build-plan/joint-NN.png        close-ups of the joints that need explaining
    docs/05-build-plan/step-NN.png         one picture per assembly step
    docs/05-build-plan/wiring.png          block-level power and stop-chain wiring (matplotlib)
A single sheet or picture can be drawn on its own, for example "sheets 103" or "steps 7", to keep
memory low. Uses .kit/build_views.py. BUILD PLAN ILLUSTRATION, PLAN NOT YET BUILT.
"""
import math
import sys
from pathlib import Path

ROOT = Path(__file__).resolve().parents[2]
sys.path[:0] = [str(ROOT / ".kit"), str(ROOT / "cad" / "src")]
import build_views as bv  # noqa: E402
from build_views import Part  # noqa: E402
from model import PARAMS as P, build_components, derived, release_state, box  # noqa: E402

OUT = ROOT / "docs" / "05-build-plan"
DWG = ROOT / "cad" / "drawings"
DATE = "2026-10-02"
D = derived(P)
C = build_components(P)

COL = {k: c.color for k, c in C.items()}
COL.update({"subframe": "#475569", "jaw": "#1E3A8A", "arms": "#0F766E", "pin": "#B45309", "cam": "#1D4ED8",
            "spring": "#D4A017", "saddle": "#A16207", "strap": "#78716C", "lever": "#DC2626", "link": "#6D28D9",
            "enc": "#0F766E", "hoop": "#F59E0B", "edge": "#1F2937", "bolt": "#111827", "stops": "#57534E",
            "donor": "#D6D3D1"})


def _fuse(shapes):
    out = None
    for s in shapes:
        out = s if out is None else out + s
    return out


S = lambda *ks: _fuse([C[k].shape for k in ks])  # noqa: E731


def part(name, shape, color, explode=(0, 0, 0), alpha=1.0):
    return Part(name, shape, color, None, tuple(explode), alpha)


def side(shape, sgn):
    """The half of a mirrored component on one side (sgn +1 right, -1 left)."""
    return shape & box(-2000, 2000, 0 if sgn > 0 else -2000, 2000 if sgn > 0 else 0, -500, 2000)


def win(sh, x0, x1, y0, y1, z0, z1):
    return sh & box(x0, x1, y0, y1, z0, z1)


def donor_yoke():
    return part("Jack yoke, pump and steer wheels (donor)", C["donor_yoke"].shape & box(-200, 400, -400, 400, -10, 345), COL["donor"])


def donor_head():
    return part("Jack frame head (donor)", C["donor_fixed"].shape & box(-200, 20, -400, 400, 0, 260), COL["donor"])


# ----------------------------------------------------------------- named parts, in build order
def made():
    return {
        "subframe": part("Subframe (top plate and welded hangers)", C["subframe"].shape, COL["subframe"]),
        "stops": part("Steering stops (2)", C["steer_stops"].shape, COL["stops"]),
        "cam": part("Cam shaft, cams and crank", C["camshaft"].shape, COL["cam"]),
        "jaw": part("Lower jaw, packing bar and M12 bolts", S("jaw", "clamp_bolts"), COL["jaw"]),
        "motors": part("Hub motors (2)", C["motors"].shape, "#111827"),
        "arms": part("Drive arms (2)", S("arm_r", "arm_l"), COL["arms"]),
        "pin": part("Pivot tubes, spacers and bolts", C["pivot_pin"].shape, COL["pin"]),
        "springs": part("Springs, saddles and lift straps", S("springs", "saddles", "straps"), COL["spring"]),
        "lever": part("Release lever, link and pins", S("lever", "link", "lever_pins"), COL["lever"]),
        "enc": part("Enclosure with feet and M8 bolts", S("enclosure", "feet", "feet_bolts"), COL["enc"]),
        "inside": part("Pack, driver, contactors, controller, rear stop", S("pack", "driver", "contactor", "controller", "estop"), "#D4A017"),
        "lid": part("Enclosure lid", C["lid"].shape, "#115E59"),
        "hoop": part("Bumper hoop and M8 bolts", S("hoop", "hoop_bolts"), COL["hoop"]),
        "edge": part("Safety edge", C["edge"].shape, COL["edge"]),
        "lidar": part("Safety scanner and its shelf", S("lidar", "lidar_bracket"), "#0EA5E9"),
        "anchors": part("UWB anchors (2)", C["anchors"].shape, "#7C3AED"),
        "tiller": part("Tiller head, beacon, stop and anchor", S("tiller", "beacon", "estop_head", "anchor_head"), "#1F2937"),
    }


ORDER = ["subframe", "stops", "cam", "jaw", "motors", "arms", "pin", "springs", "lever", "enc", "inside", "lid",
         "hoop", "edge", "lidar", "anchors", "tiller"]


# ----------------------------------------------------------------- overview
def overview():
    M = made()
    tx, tz = D["handle_top"]
    off = {"subframe": (0, 0, 0), "stops": (-170, 0, -40), "cam": (-60, 0, -170), "jaw": (-480, 0, 250),
           "motors": (0, 0, -500), "arms": (0, 0, -290), "pin": (230, 0, -250), "springs": (-150, 0, -330),
           "lever": (0, -400, 220), "enc": (0, 0, 260), "inside": (0, 0, 420), "lid": (0, 0, 600),
           "hoop": (600, 0, 60), "edge": (820, 0, 60), "lidar": (620, 0, 300), "anchors": (800, 0, 260),
           "tiller": (430 - tx + 700, 0, -tz + 900)}
    parts = []
    for k in ORDER:
        p = M[k]
        p.explode = off[k]
        parts.append(p)
    return bv.overview(parts, OUT / "overview.png", "PalletPilot prototype kit: every component, pulled apart",
                       subtitle="Numbered in build order. The donor jack is not shown. Seen from the handle end, left side and above",
                       elev=22, azim=-50, size=(11, 8.5), dpi=150, key=True)


# ----------------------------------------------------------------- making sketches
def sheets(which=None):
    import build123d as b
    M = made()
    base = dict(project="PalletPilot", date=DATE)
    out = []
    Y = donor_yoke()

    def want(n):
        return which is None or str(n) in which

    if want(101):
        out.append(bv.component_sheet(
            Part("Subframe", C["subframe"].shape, COL["subframe"]), [Y, M["arms"], M["motors"], M["hoop"]],
            dwg_no="PLP-DWG-101", title="PalletPilot subframe (top plate and welded hangers): making sketch",
            material="Steel plate 5 mm, 6 mm and 10 mm, S275 or A36; welded",
            notes=["Top plate: 5 mm steel, 295 x 400 mm. Front corners cut off at 45 degrees,",
                   "  50 mm along each edge. Pump notch: radius 62 mm, centred 15 mm in",
                   "  front of the front edge on the centre line (reaches 47 mm in).",
                   "Holes (from the front edge; sideways from the centre line):",
                   "  clamp bolts 13 mm at 49 back, 35 and 80 each side;",
                   "  enclosure feet 9 mm at 80 and 270 back, 162 each side.",
                   "Under the plate, square to it, welded both sides:",
                   "  front hangers, 6 mm, 24 x 59, inner faces 174 out, centred 75 back,",
                   "    16 mm hole 37 below the plate;",
                   "  rear hangers, 10 mm, 28 x 94, inner faces 180 out, centred 275 back,",
                   "    20 mm hole 74 below the plate;",
                   "  bumper brackets, 6 mm, 40 x 119, flush with the side edges, 215 to",
                   "    255 back, two 9 mm holes 109 below the plate at 225 and 245 back.",
                   "On top, left edge: lever bracket, 6 mm, 60 x 60, inner face 194 out,",
                   "  250 to 310 back; 12 mm pivot hole 35 up at 290 back; stop tab",
                   "  15 x 21 x 12 on its outer face, 13 mm up, 255 to 270 back.",
                   "Check: hangers square to the plate; the two hanger holes of each pair",
                   "  line up (a 16 mm and a 20 mm bar slide through)."],
            inset_view=(25, -55), **base))

    if want(102):
        out.append(bv.component_sheet(
            Part("Lower jaw", C["jaw"].shape, COL["jaw"]), [Y, M["subframe"]],
            dwg_no="PLP-DWG-102", title="PalletPilot lower jaw and packing bar: making sketch",
            material="Steel plate 10 mm; steel flat bar 34 x 15 mm (to suit the yoke)", view_shape=C["jaw"].shape, inset_view=(-25, -50),
            notes=["Jaw: 10 mm steel, 71 x 190 mm.",
                   "Packing bar: 34 mm wide, 190 long, as thick as the jack's yoke plate less",
                   "  1 mm (14 mm for the 15 mm plate drawn). Measure the yoke first.",
                   "Weld the packing bar on top of the jaw along its back edge, ends flush.",
                   "Drill four 13 mm holes through both, 49 mm from the jaw's front edge,",
                   "  35 and 80 mm each side of the centre line (drill with the top",
                   "  plate clamped on, so the holes line up).",
                   "Fit: the jaw goes under the yoke plate's back edge, the packing bar",
                   "  behind it, 2 mm clear of the edge. Four M12 bolts from below, nuts on",
                   "  the top plate: the yoke plate is gripped between the jaw and the top",
                   "  plate, with no hole drilled in the jack.",
                   "Check: with the bolts snug the jaw sits flat under the yoke plate."],
            **base))

    if want(103):
        arm = C["arm_l"].shape
        out.append(bv.component_sheet(
            Part("Drive arm", arm, COL["arms"]), [Y, M["subframe"], M["motors"], M["pin"]],
            dwg_no="PLP-DWG-103", title="PalletPilot drive arm (make 2, a left and a right): making sketch",
            material="Steel plate 10 mm; spring tab steel plate 10 mm", inset_view=(15, -40),
            notes=["Make two, a mirror pair (the left arm is drawn). 10 mm steel plate:",
                   "  three hole centres in one plane, ends rounded to 18 mm radius,",
                   "  36 mm wide between them.",
                   "Pivot hole 20 mm at the back end.",
                   "Axle hole 20 mm, 110 mm ahead of the pivot and 45 mm lower.",
                   "  Check it against the hub motor's shaft and flats.",
                   "Front end centre 195 mm ahead of the pivot and 95 mm lower.",
                   "Spring tab: 10 mm plate 44 x 44, welded square to the arm's outer",
                   "  face at the front end, its top face 90 mm below the pivot centre",
                   "  and centred on the front end. The spring sits on it.",
                   "Fit: the pivot pin passes the back hole; the motor shaft passes the",
                   "  axle hole with a 5 mm spacer between wheel and arm and a nut outside.",
                   "Check: the two arms laid back to back have their holes in line."],
            **base))

    if want(104):
        out.append(bv.component_sheet(
            Part("Pivot tubes", C["pivot_pin"].shape, COL["pin"]), [Y, M["subframe"], M["arms"]],
            dwg_no="PLP-DWG-104", title="PalletPilot arm pivot tubes, spacers and bolts: making sketch",
            material="Steel tube 20 x 3.5 mm; steel tube 30 x 5 mm; M12 bolts", inset_view=(20, -35),
            notes=["Pivot tubes (make 2): 20 mm outside, 13 mm bore, 31 mm long. Deburr",
                   "  the bore. Grease the outside before fitting.",
                   "Spacers: two tubes 30 mm outside, 20 mm bore, 5 mm long.",
                   "Each side, from the middle: tube through the arm, spacer, rear hanger;",
                   "  an M12 bolt through the bore with a 30 mm washer and a nyloc nut",
                   "  outside the hanger. The two sides are mirror images; the middle is open.",
                   "The arms must turn freely on the tubes; the bolts clamp the hangers only.",
                   "Check: each arm swings by hand through its full travel."],
            **base))

    if want(105):
        out.append(bv.component_sheet(
            Part("Cam shaft", C["camshaft"].shape, COL["cam"]), [Y, M["subframe"], M["springs"], M["arms"]],
            dwg_no="PLP-DWG-105", title="PalletPilot cam shaft, cams and crank: making sketch",
            material="Bright steel bar 16 mm; steel plate 12 mm (cams); flat bar 24 x 10 mm (crank)", inset_view=(-20, -40),
            notes=["Shaft: 16 mm bright steel bar, 419 mm long.",
                   "Cams (make 2): discs 72 mm across, 12 mm thick, with a 16 mm bore",
                   "  whose centre is 22 mm from the disc centre (the cam's throw).",
                   "Crank: 10 mm flat bar 24 wide, 74 long, ends rounded; 16 mm bore at",
                   "  one end, a 10 mm pin 18 long welded at the other, 50 mm apart.",
                   "Slide the shaft through both front hangers, then slide on a cam each",
                   "  side (outer faces 198 mm from the centre line) and the crank on the",
                   "  long end (outer face 221 mm out).",
                   "With the cams' thick side straight down and the crank pin straight",
                   "  up, drill a 5 mm hole through each hub and the shaft; fit roll pins.",
                   "Check: the shaft turns freely; cams and crank do not slip on it."],
            **base))

    if want(106):
        sad = side(C["saddles"].shape, 1) + side(C["straps"].shape, 1)
        out.append(bv.component_sheet(
            Part("Saddle and straps", sad, COL["saddle"]), [Y, M["arms"], M["cam"], part("Springs", C["springs"].shape, COL["spring"])],
            dwg_no="PLP-DWG-106", title="PalletPilot spring saddle and lift straps (make 2 sets): making sketch",
            material="Steel plate 8 mm (saddle); steel strip 12 x 4 mm (straps)", inset_view=(15, -30),
            notes=["Saddle (make 2): 8 mm steel, 44 x 34 mm. Turn a 2 mm deep ring",
                   "  groove in its underside, 34 mm across, to locate the spring top.",
                   "Straps (make 4): 4 mm steel strip 12 mm wide, 79 mm long.",
                   "  Bottom end: a 6.5 mm hole 5 mm from the end (bolted to the tab).",
                   "  Top end: a 6.5 mm wide slot, 12 mm long, ending 4 mm from the end.",
                   "Fit: one strap each side of the spring, bolted M6 to the tab and,",
                   "  through its slot, to the saddle. The slot lets the spring squash",
                   "  when a wheel rides a bump; when the lever lifts the saddle, the",
                   "  top of the slot catches and the straps lift the arm and wheel.",
                   "With the wheels down the saddle bolt sits 4 mm below the slot top.",
                   "Check: the saddle slides up and down the slots without binding."],
            **base))

    if want(107):
        out.append(bv.component_sheet(
            Part("Release lever", C["lever"].shape, COL["lever"]), [Y, M["subframe"], M["enc"], part("Link", C["link"].shape, COL["link"])],
            dwg_no="PLP-DWG-107", title="PalletPilot release lever: making sketch",
            material="Steel tube 20 x 10 x 2 mm; flat bar 20 x 10 mm; steel tube 28 mm (grip)", inset_view=(20, -60),
            notes=["Main tube: 20 x 10 x 2 mm rectangular steel tube, 376 mm long, the",
                   "  front end closed by a 2 mm plate. Pivot boss: 20 x 10 mm flat bar,",
                   "  34 long, butt-welded to the back end; 12 mm pivot hole 10 mm from",
                   "  its back end (410 mm overall).",
                   "Up-arm: 20 x 10 mm bar, ends rounded, welded at the pivot end standing",
                   "  square to the main bar; 10 mm hole 50 mm above the pivot hole.",
                   "Grip: 28 mm tube 30 mm long, welded across the front end so it",
                   "  stands out to the left, away from the enclosure.",
                   "Fit: on the bracket's pivot pin with an 11 mm spacer between the",
                   "  lever and the bracket. Wheels down: the lever lies forward,",
                   "  resting on the stop tab. Wheels up: the lever stands straight up.",
                   "The link joins the up-arm to the crank pin.",
                   "Check: the lever swings a quarter turn without touching anything."],
            **base))

    if want(108):
        out.append(bv.component_sheet(
            Part("Release link", C["link"].shape, COL["link"]), [Y, M["subframe"], M["cam"], part("Lever", C["lever"].shape, COL["lever"])],
            dwg_no="PLP-DWG-108", title="PalletPilot release link: making sketch",
            material="Steel flat bar 20 x 8 mm", inset_view=(20, -60),
            notes=["8 mm flat bar 20 mm wide, ends rounded to 10 mm radius.",
                   f"Two 10 mm holes {math.hypot(P['lever_pivot_xz'][0]-P['cam_xz'][0], P['lever_pivot_xz'][1]-P['cam_xz'][1]):.1f} mm apart between centres:",
                   "  exactly the distance from the cam shaft centre to the lever pivot,",
                   "  so the crank and the lever's up-arm stay parallel as they turn.",
                   "Fit: outboard of the crank and the lever, on their 10 mm pins, with",
                   "  a washer and split pin at each end.",
                   "Check: measure the cam shaft to lever pivot distance on the built",
                   "  subframe and match the link to it within 0.5 mm."],
            **base))

    if want(109):
        enc = S("enclosure", "feet", "lid")
        out.append(bv.component_sheet(
            Part("Enclosure", enc, COL["enc"]), [Y, M["subframe"], M["lever"]],
            dwg_no="PLP-DWG-109", title="PalletPilot enclosure, lid and feet: making sketch",
            material="Aluminium sheet 2 mm, 5052; aluminium angle 25 x 20 x 3 mm (feet)", inset_view=(25, -55),
            notes=["Box: 2 mm aluminium folded to 270 long x 300 wide x 90 tall, open",
                   "  top, corners riveted or welded; gasket on the top flange (IP54).",
                   "Lid: 2 mm aluminium, 270 x 300 with a 6 mm down-turned edge; held by",
                   "  six M5 screws into rivet nuts in the box flange.",
                   "Holes: right side, 40 mm for the disconnect, 180 from the front, 45",
                   "  up; rear face, 22 mm for the emergency stop, 80 left of centre,",
                   "  45 up; cable glands as the wiring needs, never in the lid.",
                   "Feet (make 4): 25 x 20 x 3 angle, 24 long; 9 mm hole in the flat leg",
                   "  12 from the box side. Rivet the upright leg to the box side with two",
                   "  4.8 mm rivets, 20 and 210 mm from the front, bottoms flush.",
                   "Fit: the box stands on the top plate; one M8 bolt through each foot.",
                   "Check: the lid top is no more than 320 mm above the floor when fitted."],
            **base))

    if want(110):
        out.append(bv.component_sheet(
            Part("Bumper hoop", C["hoop"].shape, COL["hoop"]), [Y, M["subframe"], M["motors"]],
            dwg_no="PLP-DWG-110", title="PalletPilot bumper hoop: making sketch",
            material="Steel rectangular tube 40 x 20 x 2 mm", inset_view=(35, -40),
            notes=["A U of 40 x 20 x 2 tube, standing 40 tall, 20 deep.",
                   "Front bar 440 long outside; two side legs 210 long outside, mitred",
                   "  at 45 degrees to the front bar and welded all round.",
                   "Side legs: two 11 mm holes in the inner face of each, 120 and 140 mm",
                   "  from the leg's open end, centred on the tube's height; set an M8",
                   "  rivet nut in each.",
                   "Fit: the inner faces of the legs bear on the subframe's bumper",
                   "  brackets; two M8 bolts each side. The tube's bottom is 90 mm above",
                   "  the floor; the front bar is 30 mm behind the wheel treads.",
                   "The safety edge rail is riveted to the front and side faces.",
                   "Check: the legs are parallel, 400 mm apart inside, within 1 mm."],
            **base))

    if want(111):
        out.append(bv.component_sheet(
            Part("Scanner shelf", C["lidar_bracket"].shape, "#64748B"), [M["hoop"], part("Safety scanner", C["lidar"].shape, "#0EA5E9")],
            dwg_no="PLP-DWG-111", title="PalletPilot safety scanner shelf: making sketch",
            material="Steel plate 3 mm", inset_view=(25, -50),
            notes=["Shelf: one flat piece of 3 mm steel plate, 118 long x 80 wide,",
                   "  laser or plasma cut. No bending.",
                   "Holes: two 5.5 mm holes, 30 apart sideways, 68 from the back edge,",
                   "  to match the rivet nuts in the top of the hoop's front bar; four",
                   "  more to suit the scanner's own mounting holes.",
                   "Fit: the shelf lies on the top of the hoop's front bar, reaching 58 mm",
                   "  back and 40 mm forward, with 2 mm of air over the safety edge. The",
                   "  scanner stands on it: scan plane 173 mm above the floor, front 10 mm",
                   "  behind the safety edge face.",
                   "Check: shelf flat and level within 1 degree; 2 mm clear of the edge."],
            **base))
    return out
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

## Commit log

2026-09-24 Initial scaffold: standard open hardware layout, CERN-OHL-S v2 + MIT licenses
    Claude-Session: https://claude.ai/code/session_01XuhhSU4W6fYhgCfURbrkut
    [bom.csv]
2026-09-25 Adopt portfolio kit v1.3.0: session commands, scale figure, 3D viewer, flow diagrams
    Adds .claude/commands (/populate, /advance-trl3, /rein-in, /refresh-media)
    so every Claude Code session starts from the standard prompts, and extends
    concept media with a 1.75 m scale figure, an interactive glTF viewer and
    system or energy flow diagrams. TRL cap 3 unchanged.
    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
2026-09-25 Kit v1.3.1: renderer fixes from the TremorTrace pilot
    Context scale parts for small objects, cutaway exclusions, and text
    labels in flow diagrams.
    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
2026-09-25 Populate palletpilot to a strong TRL 2 with concept media (batch 3)
    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
    [bom.csv]
2026-09-25 Advance palletpilot to TRL 3 (batch 3)
    Decisions approved by Amish 2026-09-25 recorded in DDR-001. TRL 4 is on hold.
    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
    [bom.csv, bumper-and-sensors.step, bumper-and-sensors.stl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]
2026-09-26 Accept all recommendations (DDR-002), switch footer to designmolecule.com, add README write-up with new inspiration point
    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
    [bom.csv, bumper-and-sensors.step, drive-module.step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]
2026-09-27 Product appearance model and photoreal renders
    Adds cad/src/product_model.py (appearance model for renders only, all main
    dimensions from model.py) and Blender renders in media/render-*.png,
    captioned with the project, repository and viewing direction. README leads
    with the product render; trl stays 3.
    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
2026-10-01 Image quality pass: legible exploded views, flow diagrams and drawing sheets
    Kit 1.6.1 image layout: the parts list sits in its own column, number bubbles sit on visible parts and never overlap, small parts get a leader, pictures are cropped to the subject, flow labels keep numbers with their units, and sheet captions and the revision table no longer overprint. Concept images, blueprint and general arrangement sheet regenerated; repo-specific labels moved clear of other text and lines.
2026-10-01 Kit 1.7.0: constructable design, illustrated build plan and design decisions register
    The design is now constructable: every part can be made and fits its neighbours, with each change recorded in a Design for construction decision record (made under Amish's 2026-09-30 instruction; ope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
    FlexHand also credits Dr. Geeti Chadha as a contribut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
    [bom.csv, bumper-and-sensors.step, bumper-and-sensors.stl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]
2026-10-02 Record Amish's approvals for PicoFlow, GravitySort and PalletPilot
    PicoFlow: clamp resistor changed to 6.8 ohm, 350 W; BOM insert size corrected to 34 mm ("I approve of your recommendations for PicoFlow and GravitySort"). GravitySort: slotted pitman pin and leaning legs that let the table reach the bump stop accepted. PalletPilot: about 40 degrees of steering each way accepted for the prototype, pitch wording corrected, and the TRL 4 aisle test made a go or no-go gate for the drive layout ("i accept your recommendations for PalletPilot"). PDFs regenerated.
2026-10-02 Record Amish's approval of the open-decision recommendations
    Amish approved the recommendation on every open decision in the design decisions register ("i approve your recommendations for all 555 open decisions.", 2026-10-02). Each decision is moved to Decisio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
2026-10-03 Carry approved follow-ups into the design and redo photoreal renders
    Amish approved the follow-up actions from the open-decision sign-off ("APPROVED CHANGES, COMPLETE THESE", 2026-10-02), the design-for-construction change tables in ten repos, the last wave's open dec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
    [bom.csv, bumper-and-sensors.step, bumper-and-sensors.stl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]
2026-10-03 Record Amish's 2026-10-03 decisions; FlatTrike fork and PotPress guard fixes
    Amish, 2026-10-03: "PalletPilot - i accept it"; "FlatTrike - i accept your design recommendation, proceed and execute the solution for fork direction or caster"; "PotPress - move forward with the four guard fixes. I accept the cost."; "GravitySort - i accept your recommendation"; "TIght Margins - i accept the margins"; "Cost over target - i accept all the cost variations and overruns". FlatTrike knuckle forks turned to trail (35 mm trail); PotPress finer mesh, small-hole plates, top beam and crank bracket covers, ISO 13857 desk check now met on paper. Registers, requirements, drawings, pictures, renders and PDFs upd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

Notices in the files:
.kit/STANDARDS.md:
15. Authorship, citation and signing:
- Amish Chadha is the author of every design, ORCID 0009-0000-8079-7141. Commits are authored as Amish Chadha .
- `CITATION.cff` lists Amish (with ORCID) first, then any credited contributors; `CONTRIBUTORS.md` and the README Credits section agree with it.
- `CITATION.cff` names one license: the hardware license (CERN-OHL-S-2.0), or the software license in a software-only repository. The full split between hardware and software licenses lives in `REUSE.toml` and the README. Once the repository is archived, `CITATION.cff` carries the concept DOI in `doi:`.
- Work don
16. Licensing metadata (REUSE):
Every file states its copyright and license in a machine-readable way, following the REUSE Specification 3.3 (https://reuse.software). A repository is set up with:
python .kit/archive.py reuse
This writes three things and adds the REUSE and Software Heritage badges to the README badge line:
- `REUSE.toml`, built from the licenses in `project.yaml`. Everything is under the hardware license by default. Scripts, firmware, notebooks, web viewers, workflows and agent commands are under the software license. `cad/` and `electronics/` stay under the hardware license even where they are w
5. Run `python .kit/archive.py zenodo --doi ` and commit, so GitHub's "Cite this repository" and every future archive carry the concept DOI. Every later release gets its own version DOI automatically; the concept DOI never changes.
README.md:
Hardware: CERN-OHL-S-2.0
